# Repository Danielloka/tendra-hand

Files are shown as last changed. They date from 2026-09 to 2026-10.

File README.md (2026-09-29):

# Tendra Hand

**An open-source, tendon-driven, 3D-printed robotic hand, built to match the dexterity of a human hand.**

**The ultimate goal:** a robot that can do what humans do (cook, do chores, use tools) just as well as a person. Not only picking things up, but understanding a task and carrying it out. The hand is the focus, because almost everything useful people do goes through their hands, and it is the hardest part to get right.

Tendra Hand starts there: a hardware + software project to build a humanoid robotic hand with the same degrees of freedom as a human hand, then the senses and AI to use it for real tasks, and to share *everything* openly: CAD files, printable parts, firmware, control software, simulation, AI models and research notes.

> 🚧 **Status: early prototype.** Phase 1: the V0 thumb and index finger are built (8 independently driven joints); focus is smooth, clean motion and a MuJoCo digital twin. Phase 2: **Tendra Hand V1**, the first full hand (5 fingers, 20 joints, smart servos), is designed and simulated, not built yet. See the [roadmap](docs/roadmap.md).

## How it works

```
┌──────────────────────────┐   USB-C (serial)   ┌───────────────────────┐        ┌──────────────┐
│ PC (Python)              │ ─────────────────▶ │ ESP32-S3              │ ─────▶ │ Motors       │
│ • high-level control     │    joint targets   │ • low-level motor     │        │ → tendons    │
│ • AI / learning          │ ◀───────────────── │   control (firmware)  │        │ → joints     │
│ • MuJoCo digital twin    │    joint states    │ • hardware abstraction│        └──────────────┘
└──────────────────────────┘                    └───────────────────────┘
```

- **Mechanics:** PLA/PETG printed skeleton (TPU fingertip pads planned). Each joint is pulled both ways by a tendon loop on its own motor.
- **Actuators:** 28BYJ-48 steppers + ULN2003 drivers today → Feetech **SCS0009** smart servos (serial bus, position feedback) next.
- **Controller:** ESP32-S3, firmware built with PlatformIO.
- **Simulation:** [MuJoCo](https://mujoco.org/), with a digital twin that mirrors and can drive the real hand.

### Current prototype: 8 DOF

| Finger | Joints |
|---|---|
| Index | MCP side-to-side, MCP bend, PIP, DIP |
| Thumb | base rotation, CMC bend, MCP, IP |

## Repository layout

| Folder | Contents |
|---|---|
| [`hardware/`](hardware/) | CAD (Fusion 360 + STEP), print files, electronics, robot description (URDF) |
| [`firmware/`](firmware/) | ESP32-S3 firmware (PlatformIO) |
| [`sim/`](sim/) | MuJoCo models, model converter, digital twin |
| [`software/`](software/) | PC-side Python: hand API, control, calibration, AI |
| [`docs/`](docs/) | Roadmap and guides |
| [`research/`](research/) | Research log, experiments, references |
| [`website/`](website/) | Project website source |
| [`media/`](media/) | Photos, videos, screenshots and diagrams of the project, with a catalog |

## Getting started

Build and setup guides will be added as each part matures. For now:
- Robot model: [`hardware/robot_description/`](hardware/robot_description/)
- Plan: [`docs/roadmap.md`](docs/roadmap.md)
- Progress and findings: [`research/log.md`](research/log.md)

## Contributing

The project is in an early stage, but ideas, issues and questions are welcome. Open an issue on GitHub.

## License

Tendra Hand is open source, with a license suited to each kind of work:

| What | License | File |
|---|---|---|
| Software: firmware, Python, simulation, AI code and models | [Apache-2.0](https://www.apache.org/licenses/LICENSE-2.0) | [`LICENSE`](LICENSE) |
| Hardware: CAD, print files, electronics, robot description (`hardware/`) | [CERN-OHL-S-2.0](https://ohwr.org/cern_ohl_s_v1.txt) | [`hardware/LICENSE`](hardware/LICENSE) |
| Documentation and research (`docs/`, `research/`, website content) | [CC BY 4.0](https://creativecommons.org/licenses/by/4.0/) | [`docs/LICENSE`](docs/LICENSE) |

In short: you may use, build, modify and sell Tendra Hand. If you distribute a modified *hardware* design, you must share its design files under the same license. Please credit the project.

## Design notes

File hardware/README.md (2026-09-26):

# Hardware

Everything physical about Tendra Hand: mechanical design, printable parts, electronics and the robot description.

| Folder | What goes there |
|---|---|
| `cad/` | Source CAD: Fusion 360 `.f3d` files plus neutral **STEP** exports (STEP opens in any CAD program) |
| `print/` | Ready-to-print **STL/3MF** files and print settings (material, infill, orientation) |
| `electronics/` | Wiring diagrams, pinouts, power budget, bill of materials (BOM) |
| `robot_description/` | Robot model files (URDF) exported from CAD, used by `sim/` |

Hardware changes are logged in `research/log.md`.

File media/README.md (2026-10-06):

# media/

All photos, videos, screenshots and diagrams of Tendra Hand live here. It's the single place for
project pictures: the website, the READMEs, the research log and Claude all use these files.

```
media/
  inbox/          drop new, unprocessed files here (not committed to git)
  photos/         photos of the real hardware
  videos/         short clips (MP4), each with a poster frame in photos/
  screenshots/    MuJoCo viewer, Fusion, website, terminal output
  diagrams/       wiring diagrams, drawings, charts (SVG or PNG)
  catalog.json    one entry per file: what it shows, alt text, caption, date, tags
  process_inbox.py  prepares the files in inbox/ and adds them to the catalog
```

## Adding pictures

1. Copy the files into `media/inbox/`. Anything straight from the phone or camera is fine.
2. Run:

   ```sh
   uv run python media/process_inbox.py
   ```

   For each picture, the script:
   - rotates it upright and shrinks it to at most 2000 px on the long side
   - **removes EXIF metadata, including GPS location** (important: the repo is public)
   - saves it as a JPEG (PNG stays PNG, so screenshots stay sharp) with a clean name like
     `2026-09-29-img-4312.jpg` in the right folder
   - adds an entry to `catalog.json` with `"todo"` fields for the description

   Videos (`.mp4`, `.mov`, `.webm`) are only moved and catalogued, not shrunk. Keep clips short
   (5–20 s) and under ~10 MB. HEIC photos (iPhone) need an extra package:
   `uv run --with pillow-heif python media/process_inbox.py`.
3. Fill in the `todo` fields in `catalog.json`, or ask Claude: *"describe the new pictures in
   media/"*. Claude looks at each file, writes the description, alt text and caption, gives it a
   better name and suggests where to use it.

Or skip the script and just tell Claude *"process the media inbox"*.

## catalog.json

Each entry describes one file. It's what lets someone (or Claude) find the right picture without
opening every file.

| Field | Meaning |
|---|---|
| `file` | Path inside `media/`, e.g. `photos/2026-09-29-index-prototype.jpg` |
| `type` | `photo`, `video`, `screenshot` or `diagram` |
| `date` | When it was taken (from the photo, otherwise the day it was added), `YYYY-MM-DD` |
| `hand` | `v0`, `v1` or `null` if it's not about one hand version |
| `description` | What's in the picture, in detail, for people and for Claude |
| `alt` | Short alt text for screen readers (one sentence) |
| `caption` | Caption to show under it on the website |
| `tags` | Topics, e.g. `index`, `thumb`, `tendons`, `electronics`, `sim`, `cad`, `printing` |
| `width`, `height` | Size in pixels (filled in by the script) |
| `poster` | Videos only: the poster frame, e.g. `photos/...-poster.jpg` |
| `used_in` | Where it's used, e.g. `website/content/data/gallery.json` |
| `todo` | What's still missing; remove it when the entry is complete |
| `public` | Optional. `false` keeps the file off the website (e.g. people who haven't agreed to be online); the website only publishes files listed here |

## Using a picture

- **Website:** the files are copied to `website/public/media/` before `npm run dev` and
  `npm run build` (`website/scripts/sync-styleguide.mjs`), so `media/photos/a.jpg` is served at
  `/media/photos/a.jpg`. Use that path in `content/data/gallery.json`, `<Figure src=… />` in MDX,
  or a log post's `cover:`. Copy `alt`, `caption`, `width` and `height` from the catalog.
- **Markdown in the repo:** link with a relative path, e.g. from `research/log.md`:
  `![Index prototype](../media/photos/2026-09-29-index-prototype.jpg)`.

Experiment folders in `research/experiments/` can keep their own generated plots. Photos of the
hardware go here.

## Rules

- Never commit a photo that still has GPS data. Run the script, or strip EXIF another way.
- Don't show people's faces or private homes without their permission.
- Names: `YYYY-MM-DD-short-subject.ext`, lowercase, hyphens.
- Licence: like the other docs and research material, the media is CC BY 4.0 (`docs/LICENSE`).

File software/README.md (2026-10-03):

# Software

PC-side Python for Tendra Hand: the `tendra` package. It holds everything that talks to the hand, real or simulated, and later the control and AI code.

## The `Hand` API

The same interface works on the simulation and on the real hand, so a script or AI policy written for one runs on the other:

```python
from tendra import RealHand, SimHand

hand = SimHand()  # MuJoCo simulation
# hand = RealHand()              # real hand; finds the ESP32 on USB automatically

hand.set_joint("index_pip", 0.8)  # radians, positive = closing
hand.set_targets([0.5] * 8)  # all joints, motor order M1..M8
print(hand.positions())
```

## Two hands: v0 and v1

| Variant | Joints | Motors | Firmware config | MuJoCo model |
|---|---|---|---|---|
| `v0` | 8 (index + thumb) | 28BYJ-48 steppers, open loop | `firmware/include/config.h` | `sim/models/tendra_hand.xml` |
| `v1` | 20 (all five fingers, 4-DOF thumb) | Feetech SCS0009 servos, 16 servos, IDs 1–16 = motor order (finger DIPs are coupled to the PIPs) | `firmware/include/config_v1.h` | `sim/models/tendra_hand_v1.xml` |

Each variant is a `HandSpec` in `tendra/joints.py` (`V0`, `V1`, or `get_hand("v1")`): joint names, limits, model path, servo IDs. Every hand object has a `.spec`, so `hand.joint_names` and `hand.num_joints` always fit the hand in use. The old module constants (`JOINT_NAMES`, `NUM_JOINTS`, `JOINT_LIMITS`, `MODEL_PATH`) still describe v0.

```python
from tendra import RealHand, SimHand

sim = SimHand(hand="v1")  # the 20-joint model
hand = RealHand()  # the variant is read from the firmware's "I" line
print(hand.spec.name)  # "v0" or "v1"; RealHand(hand="v1") refuses a v0 board

# v1 only: the servos measure where they are
hand.positions()  # measured positions (S); on v0 these are counted steps
for fb in hand.feedback():  # F: position, load %, temperature, voltage per joint
    print(fb.name, fb.position, fb.load, fb.temperature, fb.voltage, fb.online)
hand.scan_bus()  # B: IDs of the servos that answer, e.g. [1, 2, 3, ...]
hand.info()  # I: per joint scale, zero_ticks, online (for calibration)
hand.offline_mask  # after set_targets: servos that did not take it (bit i = joint i)
```

Offline servos (unplugged, no power) report `nan` in `feedback()` and ignore `set_targets` (see `offline_mask`); `raw_move` (`M`) and `J` commands to them raise `HandError`. v1 servos start limp and switch on at their measured position with the first target, so nothing jumps.

| Module | What it is |
|---|---|
| `tendra/joints.py` | Joint names, order and limits per hand variant (`HandSpec`, `V0`, `V1`): the single Python source of truth |
| `tendra/hand.py` | `Hand` base class (the interface) |
| `tendra/real_hand.py` | `RealHand`: USB serial to the ESP32 firmware, variant auto-detect, v1 feedback (`feedback`, `scan_bus`, `info`), plus calibration helpers (`zero`, `raw_move`, `set_scale`, `set_limits`) |
| `tendra/sim_hand.py` | `SimHand`: the same API on MuJoCo; `step()`/`wait()` advance the physics; `set_positions()` puts the joints at a measured pose (digital-twin mirror) |
| `tendra/retarget.py` | **Retargeting**: 21 human hand landmarks → Tendra joint angles. Fingers by direct angle measurement, thumb by damped-least-squares optimisation on the MuJoCo model (with pinch handling), One Euro smoothing, open-hand calibration. Works for v0 and v1 |
| `tendra/lite_model.py` | `load_lite_model(path)`: the same model with simplified meshes (~15 % of the triangles, masses copied), much faster to draw. `SimHand(..., lite=True)` |
| `tendra/hand_view.py` | `HandView`: draws the hand into an image on demand (offscreen renderer), mirrored, with mouse rotate/zoom, or from a fixed model camera (`camera="view"`). For OpenCV windows |
| `tendra/arm.py` | The two-arm robot: `load_arm_model()` (OpenArm v2 shoulders and elbows + Tendra forearm, wrist and V1 hands, `right_`/`left_` names), `ik_model(side)` (bare kinematic copy), `ArmIK` (damped-least-squares IK: wrist pose to arm joint targets), `POSES` |
| `tendra/scene.py` | `GraspScene`: two arms with their hands behind a table (the floating hand is gone), one hand works per episode, the other sleeps; `canon_*` mirror helpers (the left hand is seen as a right hand), objects, cameras `view`, `right_wrist`, `left_wrist`, `set_wrist_target(pos, quat, side)`, `lifted()` success check, `scripted_grasp()` |
| `tendra/synergy.py` | Hand synergies (eigengrasps): `default_synergies()` (6 human-like patterns: close, oppose, spread, hook, roll, thumb curl), `fit_synergies()` (PCA from recorded postures), `project`/`residual` |
| `tendra/grasp_env.py` | `GraspEnv`: the RL environment on `GraspScene` (actions: wrist velocity + synergies + residual; actor/critic observations; human-like reward; domain randomisation; demo-state resets from scripted grasps or teleop datasets) |
| `tendra/rl/` | `ppo.py` (PPO with asymmetric critic, normalisation, adaptive LR; `Policy` for deployment), `vec_env.py` (envs in worker processes), `train.py` (trainer with object/demo/penalty curriculum, checkpoints, `progress.csv`) |
| `tendra/wrist.py` | `WristTracker`: the operator's wrist pose from the webcam. Hand translation by Gauss-Newton on the pinhole reprojection of MediaPipe's 3D landmarks, orientation from the palm frame, mirrored into the view frame; One Euro smoothing, clutch, gain |
| `tendra/dataset.py` | `EpisodeRecorder` (records the sim state per frame, cheap), `Dataset`, `load_episode`, `render_episode` (offline, by replay), `write_preview`. Format: `info.json`, `model.mjb`, `episodes.jsonl`, `episodes/episode_NNNNNN.npz` |
| `tendra/hand_tracking.py` | Webcam + MediaPipe Hand Landmarker (pretrained network, model downloaded to `~/.cache/tendra/`), drawing helpers |
| `tendra/fake_esp32.py` | Software stand-in for the ESP32, to test without hardware: `RealHand(connection=FakeEsp32())`. v1: `FakeEsp32(hand="v1", offline={9})` emulates the servo firmware, including offline servos and joints moved by hand while limp (`move_by_hand`) |

Tests: `uv run pytest` (from the repository root). They also check that the joint names and limits match the firmware (`config.h`, `config_v1.h`) and the MuJoCo models. The v1 model tests are skipped until `sim/models/tendra_hand_v1.xml` exists.

## Planned
- Calibration tool (guided, per joint), with results saved to a file
- Trajectory generation and grasp primitives (pinch, point, power grasp)
- Learning-based control, vision-based grasping (webcam teleop: done, `sim/teleop.py`)

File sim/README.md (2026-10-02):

# Simulation

**MuJoCo** models and tools for simulating the hand and running its **digital twin** (a simulated copy that mirrors, and can drive, the real hand).

## Quick start

From the repository root (needs [uv](https://docs.astral.sh/uv/)):

```bash
uv sync                          # create the Python 3.12 environment (first time only)
uv run python sim/view.py        # open the hand in the MuJoCo viewer
uv run python sim/view.py --v1   # open the full v1 hand (20 joints, tendon-driven)
uv run python sim/view.py --wrist  # v1 on its forearm: + forearm twist and a 2-way wrist
uv run python sim/view.py --arm  # both arms: OpenArm shoulder + elbow, then the Tendra forearm, wrist and v1 hand
uv run python sim/view.py --v1 --left  # the mirrored left hand (also --wrist --left)
uv run python sim/twin.py --fake # digital twin with a software ESP32
uv run python sim/twin.py --port auto   # digital twin driving the real hand
uv run python sim/twin.py --fake --hand v1          # v1 (20 joints) with a software ESP32
uv run python sim/twin.py --port auto --mirror      # v1: the sim follows the real hand
uv run python sim/teleop.py      # webcam teleop: your hand moves the v1 twin (--hand v0, --fake, --port)
uv run python sim/grasp_teleop.py                 # DISABLED until ported to the arm scene (prints why)
uv run python sim/export_lerobot.py ~/tendra-data/datasets/grasp-sim --preview   # MP4 previews
uv run --with "lerobot[dataset]" python sim/export_lerobot.py ~/tendra-data/datasets/grasp-sim --repo-id tendra/grasp-sim --out <dir>
uv run python sim/train_grasp.py --run runs/grasp  # RL: the hand learns to grasp by itself (re-run = resume)
uv run python sim/train_grasp.py --hands right --run runs/right   # one hand only (default any: both arms, one policy)
uv run python sim/eval_grasp.py --run runs/grasp --watch   # success table / watch / --video / --record
uv run python sim/fit_synergies.py grasp-sim       # your own eigengrasps from teleop demos (for --synergies)
```

`--hand auto|v0|v1` picks the hand (auto: whatever the firmware reports, v0 without a hand). `--mirror` reverses the direction (real → sim): the sim shows the servos' measured positions and nothing is sent to the hand, so you can move the limp fingers by hand and watch. It needs position feedback, so v1 only.

Move the joints with the sliders under **Control** in the right-hand panel.

## Files

| File | What it does |
|---|---|
| `convert.py` | Turns the raw Fusion export (`hardware/robot_description/fusion_export/`) into `models/tendra_hand.xml` and fixes it along the way: PLA masses, recomputed inertias, joint names, sign convention, actuators |
| `models/tendra_hand.xml` | The generated MuJoCo model (**don't edit by hand**; re-run `convert.py`) |
| `convert_v1.py` | Turns the v1 export (`hardware/robot_description/v1_export/`: `hand_v1.json`, `meshes/`, optional `tendon_routes.json`) into `models/tendra_hand_v1.xml`: bodies, closing-positive axis signs, PLA masses, 42 tendon strands, 21 servo actuators |
| `models/tendra_hand_v1.xml` | The generated v1 model (**don't edit by hand**; re-run `convert_v1.py`) |
| `convert_v1_wrist.py` | Puts the v1 hand on its forearm (`models/tendra_hand_v1_wrist.xml`): `forearm_rot` (twist, OpenArm's J5 motor), a 2-way wrist gimbal (`wrist_flex`, `wrist_dev`) in a 20 mm gap between forearm and palm. Every servo strand runs through one site on the wrist centre (PTFE sheaths through a hollow wrist), so wrist motion never changes a strand's length. Input is the generated `tendra_hand_v1.xml`, so it follows every `convert_v1.py` change |
| `models/tendra_hand_v1_wrist.xml` | The generated wrist model (**don't edit by hand**; re-run `convert_v1_wrist.py`). The full arm (OpenArm + this) is built in Python: `tendra.arm` |
| `convert_v1.py --side left`, `convert_v1_wrist.py --side left` | Build the mirrored left hand and wrist (`models/tendra_hand_v1_left.xml`, `tendra_hand_v1_wrist_left.xml`) from `hardware/robot_description/v1_export_left/` (made by `hardware/cad/mirror_export.py`). With no `--side` both sides are built |
| `view.py` | Interactive viewer (`--v1` full hand, `--wrist` on its forearm, `--arm` both arms, `--left` the mirrored left hand) |
| `twin.py` | **Digital twin**: slider targets are sent to the real hand (rate-limited, only on change); the terminal shows real-vs-sim difference. v1 adds `--mirror` (real → sim) |
| `teleop.py` | **Webcam teleoperation**: MediaPipe hand tracking → `tendra.retarget` → the twin (and optionally the real hand). One window: camera image + the hand, drawn only when it moves (≤ 30 fps). Defaults are tuned for a slow laptop: kinematic mode (no servo delay; `--physics` for the tendon sim), simplified meshes, no shadows, tendons hidden (`--tendons`), MuJoCo's viewer only with `--viewer`. Mouse on the hand: drag rotates, wheel zooms. Prints a speed summary on exit. Keys in the camera window: C calibrate (hand open and flat), SPACE pause, M flip palm side, Q quit |
| `grasp_teleop.py` | **Disabled** (2026-10-02): the webcam grasp teleop drove the floating hand, which was removed. It is a stub that explains this; the old version is in git history. To port: map the webcam wrist pose to `scene.set_wrist_target(pos, quat, side)` with a pose the arm can reach |
| `export_lerobot.py` | Renders recorded episodes offline (replaying the saved sim state) and exports them to a Hugging Face **LeRobot** dataset (v3.0 format, lerobot 0.6.1, run with `uv run --with "lerobot[dataset]"`), or only MP4 previews (`--preview`). Successful episodes only unless `--all` |
| `train_grasp.py` | **Reinforcement learning:** PPO trains the V1 hand on its arm (OpenArm's shoulder and elbow + Tendra's forearm and wrist; two arms, `--hands right|left|any`, one policy for both via a mirror) to grasp and lift (`tendra.grasp_env`, `tendra.rl`): synergy actions, human-like rewards, demo-state starts, object and penalty curriculum, domain randomisation, parallel worker processes. Writes `runs/<name>/` (`progress.csv`, `latest.pt`, `best.pt`); `--smoke` for a 30 s check. Design and research: `research/ai/grasp-rl.md` |
| `eval_grasp.py` | Evaluates a trained policy on fixed spawns (success, lift, time, smoothness, effort, synergy residual); `--watch` live window, `--video out.mp4`, `--record <name>` saves successful rollouts as a teleop-format dataset (RL teacher → imitation student) |
| `fit_synergies.py` | PCA "eigengrasps" from recorded teleop datasets → `.npz` for `train_grasp.py --synergies` |
| `tests/` | Model sanity checks, twin, mirrored left hand (`test_v1_left.py`): `uv run pytest` |

After a new Fusion export, or a change to `convert.py` / `convert_v1.py`:
```bash
uv run python sim/convert.py && uv run pytest       # v0
uv run python sim/convert_v1.py && uv run python sim/convert_v1_wrist.py && uv run pytest    # v1 (+ wrist)
```
The tests fail if a generated model is out of date.

## Model conventions

- Joints and actuators are listed in **motor order** (M1…M8): `index_dip, index_pip, index_mcp_flex, index_mcp_abd, thumb_ip, thumb_mcp, thumb_cmc_flex, thumb_cmc_rot`
- **Positive = closing the hand**, and 0 = straight. Angles are in radians.
- Actuators are simple position controllers standing in for the stepper + tendon, and will be tuned against the real hand later.

## v1 model (full hand, tendon-driven)

- **20 joints, 16 actuators** in **servo-ID order** (same as `firmware/include/config_v1.h`): `index_pip, index_mcp_flex, index_mcp_abd, thumb_ip, thumb_mcp_flex, thumb_cmc_flex, thumb_cmc_rot`, then middle, ring, little (`pip, mcp_flex, mcp_abd` each). Actuator names = joint names. The four finger DIPs have no actuator: each follows its PIP (DIP ≈ 0.75 × PIP) through a joint equality `<f>_dip_coupling` that uses the coupling linkage's exact curve (`hardware/cad/dip_linkage.py`).
- **Sign convention** (positive = closing), worked out automatically from the geometry, because Fusion's axis signs are arbitrary: finger flexion bends toward the palm (-Y); finger `mcp_abd` moves toward the thumb (+X); `thumb_cmc_rot` swings the thumb across the palm (-X); thumb flexion (`cmc_flex`, `mcp_flex`, `ip`) curls it toward the fingers (+Z).
- **Tendons.** Every servo joint has one loop of two strands, `<joint>_flex` and `<joint>_ext` (32 strands). The loop wraps a drum on the joint's child segment (7 mm for finger `mcp_flex`, 7.5 mm for `thumb_cmc_rot`, 6 mm otherwise) and is tied to it, so the joint changes the strand length by exactly the drum radius per radian: the flex strand shortens and the ext strand lengthens by the same amount, and the loop stays tight. Strands of more distal joints cross every joint they pass **exactly on its axis**, so those joints don't change their length (no coupling). In the palm and forearm the strands follow `tendon_routes.json` down to the spool tangent points. Each finger's DIP-PIP coupling bar is a grey passive tendon `<f>_dip_link` between its two pins (on the proximal and distal phalanges); its length stays constant along the coupling curve (tested), which checks the linkage geometry.
- **Actuation.** One actuator per servo pulls its joint's flex strand. `ctrl` is the **joint angle in radians** (0 = joint straight); the servo turns `servo_per_joint` = drum / 5 mm spool times that (1.2–1.5). The gains are SCS0009-like: kp 2 N·m/rad, torque limit 0.095 N·m at the servo (half of stall, ≈19 N of tendon force), both scaled to the joint by the ratio. MuJoCo tendons can push as well as pull, so one actuator on the flex strand stands in for the whole loop. Pretension, friction and line stretch are not modelled.
- Keyframes `open` and `fist`.
- **Known limits:** collisions use convex hulls. Palm ↔ thumb_metacarpal is excluded because the palm's hull fills the pocket for the thumb base. The real parts only meet near `thumb_cmc_flex` = 80°, which the sim therefore misses. Toward a straight neighbour, a finger can adduct only about 4–5° before touching it (8 mm gap). That is real geometry.

NVIDIA Isaac Sim/Lab may be added later on a machine with an NVIDIA GPU.

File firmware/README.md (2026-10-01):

# Firmware

Low-level motor control running on the **ESP32-S3-N16R8**, built with **PlatformIO** (Arduino framework, C++17).
The PC sends joint targets in radians over **USB-C** (native USB serial). The ESP32 moves the motors there smoothly.

One code base builds firmware for two hands:

| Build env | Hand | Joints | Motors | Config |
|---|---|---|---|---|
| `tendra_s3` (default) | **v0** prototype (thumb + index) | 8 | 28BYJ-48 steppers + ULN2003 boards | `include/config.h` |
| `hand_v1_servo` | **v1** full hand | 20 | Feetech **SCS0009** smart servos on one bus, via the **FE-URT-1** | `include/config_v1.h` |

## Build, flash, talk to it

From this folder (`firmware/`), or use the PlatformIO buttons in VS Code:

```bash
pio run                          # build v0 (the default env)
pio run -e hand_v1_servo         # build v1
pio run -t upload                # flash v0 (ESP32 on USB-C); add -e hand_v1_servo for v1
pio device monitor               # type commands, see replies (Ctrl+C to quit)
```

If the upload can't connect: hold **BOOT**, tap **RESET**, release BOOT, and try again.

## How it's built

| File | Role |
|---|---|
| `include/config.h` | v0: **pin map**, joint names/limits (same order as the sim), speed/acceleration defaults |
| `include/config_v1.h` | v1: servo IDs, joint names/limits, calibration defaults, bus pins/baud, speed limits |
| `src/motor_driver.h` | **HAL interface**: one joint actuator, in radians, with optional feedback. The rest of the code only uses this. |
| `src/uln2003_stepper.*` | v0: 28BYJ-48 + ULN2003 driver (half-step), implements `MotorDriver` |
| `src/scs0009_servo.*` | v1: SCS0009 servo driver, implements `MotorDriver` |
| `src/scs_protocol.h` | v1: SCS packet building, checksum, reply parser, register map (pure C++) |
| `src/scs_bus.*` | v1: `ScsBus` — ping, read/write registers, sync write, feedback; over an abstract byte port |
| `src/scs_uart_port.h` | v1: the byte port on an ESP32 hardware UART |
| `src/servo_calibration.h` | v1: joint angle ↔ servo ticks (scale, zero, direction) |
| `src/motion_profile.h` | Smooth motion: accelerate, cruise, brake (trapezoidal profile), handles new targets mid-move. Used by both hands. |
| `src/main.cpp` | Safe startup, main loop, serial command protocol (v0/v1 picked by `TENDRA_HAND_V1`) |
| `test/host/` | Unit tests that run on the PC (motion profile; SCS protocol, bus, calibration and servo driver) |

## Serial protocol (text, one command per line)

The same protocol for both hands; only the number of joints *N* changes (v0: 8, v1: 20).
Joints are numbered **1–N = motors M1–MN** (v1: motor number = servo ID). Angles are in **radians**, and **positive = closing the hand**.

- v0 joints: `index_dip, index_pip, index_mcp_flex, index_mcp_abd, thumb_ip, thumb_mcp, thumb_cmc_flex, thumb_cmc_rot`
- v1 joints: `index_dip, index_pip, index_mcp_flex, index_mcp_abd, thumb_ip, thumb_mcp_flex, thumb_cmc_flex, thumb_cmc_rot, middle_dip, middle_pip, middle_mcp_flex, middle_mcp_abd, ring_dip, ring_pip, ring_mcp_flex, ring_mcp_abd, little_dip, little_pip, little_mcp_flex, little_mcp_abd`

| Command | Meaning | Reply |
|---|---|---|
| `P q1 … qN` | set all N targets | `OK` (v1: `OK offline <mask>` if some servos don't answer; those don't move) |
| `J i q` | set target of joint *i* | `OK` (v1: `ERR joint offline`) |
| `S` | status | `S q1 … qN moving_mask`. v0: counted steps. **v1: measured positions** (real → sim) |
| `F` | feedback, per joint `q,load,temp,volt` | `F 0.1234,12.5,31,5.0 …`; `nan,0,0,0` if the joint has no data (always on v0). *load* is % of max torque, positive = pulling toward closing; *temp* °C; *volt* V |
| `X` | stop all, smoothly | `OK` |
| `R` | release all: v0 coils off, **v1 torque off** (joints go limp) | `OK` |
| `Z` | current pose = zero | `OK` |
| `M i n` | raw move joint *i* by *n* native units, **ignores joint limits** (calibration). v0 steps (max ±4096), v1 servo ticks (max ±300, still kept inside 0–1023) | `OK` |
| `K i s` | set joint *i* scale in native units per joint radian (v0 steps/rad, v1 ticks/rad) | `OK` |
| `V i v a` | max velocity (rad/s) and acceleration (rad/s²) of joint *i* (`0` = all) | `OK` |
| `B` | **v1 only:** scan the bus (IDs 0–253, ~0.4 s) | `B 1 2 3 …` (IDs that answered) |
| `I` | firmware info + scales | v0: `I tendra-hand fw 0.1.0 joints=8 name:scale …`; v1: `I tendra-hand fw 0.4.0 hand=v1-servo joints=16 name:ticks_per_rad:zero_ticks:online …` |

Targets are clamped to the joint limits. v0: coils switch off after 1 s without motion. v1: servos keep holding (torque on) until `R`.

## v1: SCS0009 servos

### Wiring (FE-URT-1 as signal converter)

| ESP32-S3 | FE-URT-1 | Notes |
|---|---|---|
| GPIO **17** (UART1 TX) | TX | |
| GPIO **18** (UART1 RX) | RX | |
| GND | GND | common ground with the servo supply |

GPIO 17/18 are ordinary pins: not strapping pins (0, 3, 45, 46), not native USB (19/20), not UART0 (43/44), not flash/PSRAM (26–37), not the RGB LED (48). Change them in `config_v1.h`.
Some FE-URT-1 boards have TX/RX **silk-screened the wrong way round**: if `B` finds nothing, swap the two wires.
The FE-URT-1 switches the half-duplex bus direction by itself. If it echoes our own bytes back to RX, `ScsBus` skips the echo automatically.
Bus: **1,000,000 baud**, 8N1 (the SCS0009 default). Every servo needs a unique ID = its motor number (1–20); set IDs one servo at a time with Feetech's FD software over the FE-URT-1's USB port.
Power the servos from their own supply (SCS0009: 4–7.4 V). 16 servos under load draw several amps: size the supply and wiring for it, and keep the ESP32 on USB.

### How it moves

- Each servo has an **absolute position sensor** (0–1023 ticks over ~300°, ≈195.6 ticks/rad, centre 512). No homing is needed; the firmware always knows where each joint is.
- The firmware ramps each goal with the same trapezoidal profile as v0 (one tick at a time, ≤ 400 ticks/s) and streams the goals of all moving servos every **20 ms** in one **SYNC WRITE** packet. So even a big target jump becomes a smooth, speed-limited move.
- As a second limit, every goal carries the servo's **goal speed** register (`kServoGoalSpeed`, never 0, because 0 means "full speed").
- Feedback (position, load, voltage, temperature) is read from one servo every 2 ms, round robin (all 20 in ~40 ms). A servo that misses 3 replies counts as **offline** and is only retried once per second.

### Calibration: joint angle ↔ servo ticks

`ticks = zero_ticks + (invert ? -1 : 1) · ticks_per_rad · q`, with `ticks_per_rad = servo_per_joint · 195.57`.

- `servo_per_joint` = servo radians per joint radian = *r*<sub>joint drum</sub> / *r*<sub>spool</sub> (same tendon length both sides). Set from the design (since 0.4.0): 5 mm spools on every servo, so **1.4** for finger `mcp_flex` (7 mm drum), **1.5** for `thumb_cmc_rot` (7.5 mm) and **1.2** for the rest (6 mm); calibrate per joint once built. The finger DIPs have no servo (coupled to the PIP), so V1 has 16 servos for 20 joints.
- `zero_ticks` = servo reading with the joint straight. Default 512 (servo centred when the tendon is tied).
- `invert` if more ticks opens the joint.

### v1 safety rules

- **Never moves on boot.** `setup()` broadcasts *torque off* to every servo, then switches each one off again and reads its position. Nothing moves until a `P`/`J`/`M` command.
- On the first command, a joint's goal is first set to **where it is now**, then torque comes on, then it ramps to the target. No jump.
- A servo that has **never answered cannot be switched on** (its position is unknown): `J`/`M` reply `ERR joint offline`.
- `R` = torque off for all (broadcast + each servo). `X` = smooth stop, holding position.
- The firmware only writes the SRAM registers (torque, goal position/time/speed). It never writes EPROM (ID, baud, angle limits).

### v1 first power-on checklist

1. Flash `hand_v1_servo` with **only USB connected**. Send `I`: 20 joints, all `:0` (offline).
2. Power the servos. Send `B`: it should list the IDs you connected. Send `I` again (online joints end in `:1`) and `F` to see positions, voltage and temperature.
3. Straighten the joints by hand (they are limp), then send `Z`, then `I`; copy the `zero_ticks` values into `config_v1.h`.
4. One joint at a time: `M i 30` (≈9° at the servo), then `M i -30`. Check that the right joint moves and **positive closes** it; otherwise set `invert = true` in `config_v1.h`.
5. Calibrate scale: `M i 150`, measure the joint angle, then `K i <150 / angle_in_rad>`. Write it into `config_v1.h` as `servo_per_joint = value / 195.57`.
6. Only then use `J i q` / `P ...`. Keep `R` ready (and a power switch).

## Safety rules (v0 steppers)

- At boot, all motor pins go LOW and **nothing moves until a command arrives**.
- **PSRAM must stay disabled**: GPIO 35–37 drive motors 6 and 7 (see `platformio.ini`).
- Steppers are open loop: the firmware *counts* steps. Straighten all joints by hand before power-up (or send `Z` after straightening).
- Stay near a power switch during first tests. A tendon that is too tight or a wrong direction can pull hard.

## First power-on checklist (v0, one motor at a time)

1. Flash with **only USB connected** (motor power off). Open the monitor and send `I`, which should list 8 joints.
2. Connect the motor power. Straighten all joints by hand, then send `Z`.
3. For each motor: send `M i 200` (a small move, ~18°), then `M i -200`.
   - Check that the right joint moves and that **positive closes** the joint. If it opens instead, set `invert = true` for that joint in `config.h`.
4. Calibrate scale: send `M i 1000`, measure the joint angle (in degrees), then `K i <1000 / angle_in_rad>`. Write the value down (it'll go into `config.h`).
5. Only then use `J i q` / `P ...` with real angles.

## Host tests

Run from `firmware/` (a throwaway C++ compiler from the `ziglang` Python package, no install needed):

```bash
uvx --from ziglang python -m ziglang c++ -std=c++17 -O2 -w -Isrc test/host/test_motion_profile.cpp -o .pio/test_motion_profile.exe && .pio/test_motion_profile.exe
uvx --from ziglang python -m ziglang c++ -std=c++17 -O2 -w -Isrc -Iinclude test/host/test_scs.cpp src/scs_bus.cpp src/scs0009_servo.cpp -o .pio/test_scs.exe && .pio/test_scs.exe
```

`test_scs.cpp` checks packet bytes and checksums against hand-computed values, the reply parser (noise, bad checksums), `ScsBus` against a fake servo bus with and without echo, angle ↔ tick conversion, and the servo driver's boot safety, ramp speed and limit clamping.

## Sources and licenses

The SCS code here is written from scratch (Apache-2.0, like the rest of the firmware). The protocol and register map were taken from Feetech's documentation and read (not copied) from the official [FTServo_Arduino](https://github.com/ftservo/FTServo_Arduino) library (`SCS.cpp`, `SCSCL.h/.cpp`). No third-party code is vendored.

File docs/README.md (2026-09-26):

# Docs

Project documentation: roadmap, build guides, assembly instructions, calibration and usage guides.

- `roadmap.md`: development phases, from thumb + index to full AI-controlled hand

This folder can also feed the project website.

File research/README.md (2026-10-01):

# Research

Research hub: lab notebook, experiments, references.

- `log.md`: dated research log (experiments, results, decisions, ideas)
- `ai/`: embodied-AI research hub: bimanual pole robot vision, AI architecture, staged roadmap, maths, resources, ideas
- `experiments/`: data and scripts for individual experiments
- `references/`: notes on papers and related projects
  - `references/hands/`: the state of the art in robot hands (1X NEO, humanoid company hands, ORCA/LEAP/Aero and other open-source hands, tendon mechanics, sensing, actuators and control). Start with its `README.md`, which has the overview and the prioritised plan for Tendra.

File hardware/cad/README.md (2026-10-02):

# CAD

Source design files for the hand.

- `*.f3d`: Fusion 360 archives (the source of truth)
- `*.step`: neutral exports so people without Fusion can open and modify the design
- `fusion_scripts/`: Fusion API scripts (see its README). `TendraHandV1/` builds the full v1 hand.
- `tendon_router.py`: v1 tendon routes + forearm servo layout (single source of truth for the CAD channels and the MuJoCo tendons). Run `uv run python hardware/cad/tendon_router.py`; tests in `tests/` (run by `uv run pytest`).
- `dip_linkage.py`: the DIP-PIP coupling bar of each V1 finger (pin positions found per finger from the middle-phalanx length in `hand_v1.json`, so DIP ≈ 0.75 × PIP). `tendon_router.py` writes the result into `tendon_routes.json` (`coupling.linkages`); `uv run python hardware/cad/dip_linkage.py` prints it.
- `mirror_export.py`: reflects `v1_export/` into `../robot_description/v1_export_left/` (the left hand for the two-arm sim; mirror plane x = -33.5 mm). `--check` reports if it is stale. Re-run after every `tendon_router.py` or Fusion export change.

When the design changes, export both, and re-export the URDF into `../robot_description/fusion_export/`.

## Tendra Hand V1

Fusion design **"Tendra Hand V1"** (a copy of "Hand assebly"). Workflow after a change:
1. `uv run python hardware/cad/tendon_router.py` (if routes/layout changed) and `uv run pytest hardware/cad/tests`
2. In Fusion, run the `TendraHandV1` stages (each skips itself if already applied), then stage `export`
3. `uv run python sim/convert_v1.py && uv run pytest`

- `spool_v0.py`: parametric tendon spool for the V0 hand's 28BYJ-48 steppers (OpenCASCADE, writes `hardware/print/v0/spool_r<radius>.stl`). Run: `uv run --with cadquery-ocp python hardware/cad/spool_v0.py [--radius 5]`.

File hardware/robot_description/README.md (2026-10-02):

# Robot description

Kinematic/physical models of the hand.

- `fusion_export/`: the **raw, unedited** export from Fusion 360 (made with the `fusion2urdf` plugin, a ROS 1 package format).
  Don't edit it by hand: re-export from Fusion instead, so nothing gets lost.
  Its `LICENSE` and `package.xml` are template leftovers from the plugin and don't describe this project.

- `v1_export/`: the v1 hand (20 joints, 16 servos), written by the `TendraHandV1` Fusion script (stage `export`): `hand_v1.json` (parts + joints, world mm, all joints at 0; Fusion's axis signs are arbitrary), `meshes/*.stl`, and `tendon_routes.json` from `hardware/cad/tendon_router.py`. `sim/convert_v1.py` turns it into `sim/models/tendra_hand_v1.xml`.
- `v1_export_left/`: the **mirrored left hand**, generated (don't edit) from `v1_export/` by `hardware/cad/mirror_export.py` (reflection across x = -33.5 mm, the hand's mirror plane; STL winding reversed). `uv run python hardware/cad/mirror_export.py` rebuilds it, `--check` fails if it is stale; `uv run pytest` checks that too. Re-run after every new `v1_export/`.

The cleaned models (correct PLA masses, recomputed inertias, descriptive joint names, flexion-positive axes, MuJoCo MJCF) are **generated** from this export by a script in `sim/`.

### Known issues in the current export
- Material is set to steel (total mass 821 g instead of about 130 g)
- Inertias rounded to 1e-6; two are invalid
- Placeholder effort/velocity limits (100)
- Thumb joints 7 and 8 have opposite axis signs

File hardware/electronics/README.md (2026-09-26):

# Electronics

Wiring, pinouts and power for the hand.

**Current setup (Phase 1):** ESP32-S3-N16R8, 8x 28BYJ-48 steppers, 8x ULN2003 drivers, separate 5 V / 2 A motor supply.
**Planned:** Feetech SCS0009 smart servos on one bus via an FE-URT-1 adapter.

The authoritative pin map lives in `firmware/` (config header) and `CLAUDE.md`. Keep diagrams here in sync with it.

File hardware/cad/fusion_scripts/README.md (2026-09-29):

# Fusion scripts

Python scripts that run inside Fusion (Autodesk Fusion API). Each script lives in its own folder with a `.py` and a `.manifest` of the same name.

**Run one:** Fusion → **Utilities → Scripts and Add-Ins** → **+** (add from device) → pick the script's folder → select it → **Run**.

Run design-changing scripts on a **copy** of the design, or check the version history afterwards.

| Script | What it does | Changes the design? |
|---|---|---|
| `TendraInspect` | Writes `inspect_output.txt` with components, bodies, joints and axis positions (world mm) | No |
| `TendraPipPinch` | Fills the fingertip tendon slot at the index PIP and adds a 1.2 mm hole on the joint axis (see `research/experiments/2026-09-27-pip-pinch/`) | Yes: 2 timeline features, asks first |
| `TendraIndexPinch` | Index knuckle: 1.4 mm hole on the MCP flex axis and a 1 mm slit on the sideways axis (see `research/experiments/2026-09-27-index-pinch/`). Needs the finger straight | Yes: 2 features per change, asks first |
| `TendraHandV1` | Builds the v1 hand in the "Tendra Hand V1" design, in stages: `fingers` (middle/ring/little from the index), `thumb` (keeps the 4-DOF thumb), `names`, `thumb_unhinge` (one-off: removes the 5th-DOF hinge from designs built before 2026-09-29), `thumb_base` (plate 4 mm lower, hollow journal, r 7.5 cmc_rot drum, hanger for the cmc_flex pin; see `research/experiments/2026-09-29-thumb-routing/`), `thumb_meta` (cmc_flex drum on the metacarpal, cleared around the strands), `palm` (full palm, deeper thumb bay with journal bearing and pin hole, 42 tendon channels), `forearm` (21 SCS0009 + spools, sheath stops in the wrist plate); `export` writes STLs + joints to `hardware/robot_description/v1_export/`. Reads `tendon_routes.json` | Yes: refuses to run on any other design |

Output files (`*_output.txt`) are not committed.

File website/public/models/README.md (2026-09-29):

# 3D models

The website shows a **procedural placeholder hand** until a real model is put
here. To switch to the real hand:

1. Export the model as `public/models/hand.glb` (steps below).
2. In `src/components/three/model.ts`, change the one line to
   `export const HAND_MODEL_URL: string | null = "/models/hand.glb";`
3. Open `/dev/hand` (the hand lab) and check every preset and joint slider.

Keep the file small: aim for **under 3 MB** (it loads on the homepage).

## Coordinate frame

| | |
|---|---|
| Up (+Y) | toward the fingertips (hand pointing up) |
| Toward the camera (+Z) | the **palm** side |
| +X | the **thumb** side (it's a right hand seen from the palm) |
| Units | metres (the site rescales the model to a fixed height anyway) |

## Node names (this is what makes the hand move)

Each joint needs an **empty/node named exactly like the joint**, sitting at the
joint's pivot. Everything that should move with the joint (the next finger
segment, and all segments after it) is a **child** of that node.

- The node's **origin** is the pivot point.
- The node's **local X axis** is the rotation axis.
- A **positive** rotation about local X is "closing the hand" (the project's
  sign convention, see `CLAUDE.md`): fingers bend toward the palm, the thumb
  swings across the palm, `index_mcp_abd` moves the index toward the thumb.
  If a joint bends the wrong way, flip that node's X axis in Blender
  (rotate the empty 180° about its Y or Z axis and re-parent).

Joint names (all 17; the first 8 exist on the real prototype):

```
thumb_cmc_rot  thumb_cmc_flex  thumb_mcp  thumb_ip
index_mcp_abd  index_mcp_flex  index_pip  index_dip
middle_mcp_flex  middle_pip  middle_dip
ring_mcp_flex    ring_pip    ring_dip
little_mcp_flex  little_pip  little_dip
```

Hierarchy example for the index finger:

```
palm
└─ index_mcp_abd        (empty at the knuckle)
   └─ index_mcp_flex    (empty at the knuckle)
      ├─ index_proximal (mesh)
      └─ index_pip      (empty at the middle joint)
         ├─ index_middle (mesh)
         └─ index_dip   (empty at the fingertip joint)
            ├─ index_distal (mesh)
            └─ index_tip    (optional empty at the fingertip)
```

Optional extras:

- `thumb_tip`, `index_tip`, `middle_tip`, `ring_tip`, `little_tip`: empties at
  the fingertips. The glowing tendon lines run through the joint nodes and end
  at these; without them a tendon ends at the last joint.
- The tendon lines sit ~1 cm behind each joint along the node's **local −Z**
  (the back of the hand), so keep local +Z pointing to the palm side.

What happens without the joint nodes: the model still shows, lights, glows
and turns, but nothing bends, and there are no labels, tendons or exploded
view.

How the effects use the nodes:

| Effect | Uses |
|---|---|
| Joint bending | rotation about local X, on top of the node's rest pose |
| Labels (MCP / PIP / DIP / CMC / IP) | pinned to the joint node's origin |
| Tendons | a curve through the joint nodes (+ `*_tip`), offset to the back |
| Exploded view | each joint node slides outward along its offset from its parent |
| Wireframe | automatic outline + sharp edges of every mesh |

Joint ranges (how far `1.0` on a slider turns) are in
`src/components/three/rig.ts` (`JOINT_RANGE`).

## Export: Fusion 360 → Blender → glTF

1. **Fusion 360:** export each body, or the whole design, as **OBJ** or
   **STEP**/**FBX** (File → Export). Use the assembly where each finger
   segment is its own body.
2. **Blender** (free): import it. Check the scale (1 unit = 1 m; Fusion often
   exports millimetres, so scale by 0.001 and apply the scale with
   Ctrl+A → Scale).
3. Rotate the hand so it matches the frame above (fingers up +Y, palm facing
   the front). Blender is Z-up; the glTF exporter converts to Y-up for you when
   **+Y Up** is ticked (the default).
4. Add an **Empty** (Shift+A → Empty → Plain Axes) at each joint, name it,
   rotate it so its X axis is the joint axis, and parent the segments to it as
   in the hierarchy above (select child, then parent, Ctrl+P → Object (Keep
   Transform)).
5. Reduce detail: a Decimate modifier (ratio 0.2–0.5) on dense CAD meshes, and
   apply it. Screws and tiny parts can go.
6. Materials: one simple Principled BSDF per material (the site adds its own
   lighting, rim glow and wireframe on top). No textures needed.
7. File → Export → **glTF 2.0**: Format **glTF Binary (.glb)**, Include →
   *Selected Objects* or *Visible Objects*, Transform → **+Y Up**, Data →
   Mesh: *Apply Modifiers*. **Draco compression** is optional: it makes the
   file much smaller, but the decoder is then downloaded from Google's CDN
   (gstatic.com) on first load.
8. Save as `public/models/hand.glb`, set `HAND_MODEL_URL`, and test in
   `/dev/hand`.

## Current model

`hand.glb` is made straight from the STEP file by a script (no Blender):

```
uv run --with cadquery-ocp --with pygltflib python website/scripts/step-to-glb.py
```

It reads `hardware/cad/Hand assebly.step` (thumb + index prototype, 9 parts,
~13k triangles, 0.4 MB) and rigs it automatically: each part is matched to a
body of the MuJoCo model (`sim/models/tendra_hand.xml`) by its bounding box, and
the joint nodes are placed at the URDF joint pivots with the sim's axis signs
(positive = closing). `index_tip` / `thumb_tip` mark the fingertips. The STEP
and the URDF export must come from the same Fusion design; the script stops
if a sim body has no matching part.

`index_mcp_abd` and `thumb_cmc_rot` have sideways axes, so the tendon line
skips them and runs through the next joint (see `gltfRig.ts`).

## `hand-v1.glb` (project page)

A **static, unrigged** model of the full 5-finger Tendra Hand V1 (palm, fingers and thumb, no servos
or forearm), shown spinning in the project page's hero (`components/three/SpinHand.tsx`). Made from
the Fusion export by `website/scripts/v1-to-glb.py` (command in its docstring); re-run it after a new
V1 export. About 1.6 MB.

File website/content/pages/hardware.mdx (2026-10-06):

---
title: Hardware
kicker: Build it yourself
lead: "Printed parts, small motors, one microcontroller and some cord. Here is what goes into the prototype and where to find the files."
description: "The parts, files, print settings, motors and electronics behind the Tendra Hand thumb and index prototype."
---

## What the prototype is made of

The current prototype is a thumb and an index finger with 8 joints. It has three layers:

<CardGrid>
  <Card title="Printed skeleton" kicker="Mechanics">
    The bones of the fingers, printed in PLA or PETG. Soft TPU fingertip pads are planned for a better grip.
  </Card>
  <Card title="Tendons" kicker="Motion">
    Each joint has one closed loop of cord wound on a spool with a 1 cm radius. The motor turns the spool one way to bend the joint and the other way to straighten it.
  </Card>
  <Card title="Motors and electronics" kicker="Power">
    8 small stepper motors, one per joint, each with its own driver board, all controlled by one ESP32-S3.
  </Card>
</CardGrid>

## Design files

All hardware files live in the [`hardware/`](https://github.com/Danielloka/tendra-hand/tree/main/hardware) folder on GitHub.

| Folder | What's inside |
|---|---|
| `hardware/cad/` | The source design: Fusion 360 files, plus STEP files that open in any CAD program |
| `hardware/print/` | Ready-to-print STL and 3MF files, with print settings |
| `hardware/electronics/` | Wiring, pin map and power budget |
| `hardware/robot_description/` | The robot model exported from Fusion 360, used by the simulation |

<Callout type="note" title="What is in the repository today">
  The repository holds the full hand as a STEP file (it opens in any CAD program), the Fusion 360 scripts that build the V1 design, the robot model with a 3D mesh of every part, and a spool you can print. A complete set of print-ready files is still being prepared and will be added to `hardware/print/`.
</Callout>

## Bill of materials

Everything needed for the thumb and index prototype, plus the planned servo upgrade.

<BomTable />

## Print settings

The final settings haven't been written down yet. These are common starting points for small mechanical parts, not tested values for this hand.

| Setting | Starting point |
|---|---|
| Material | PLA or PETG |
| Nozzle | 0.4 mm |
| Layer height | 0.2 mm (0.12 to 0.16 mm for small finger parts) |
| Walls | 3 or more perimeters, so joint holes stay strong |
| Infill | 20 to 40 % |
| Supports | Only where needed; orient parts to avoid them in joint holes |
| Orientation | Lay parts so layers don't split along the direction the tendon pulls |

The simulation model assumes solid plastic and works out to about 131 g. Real printed parts are lighter because they aren't solid.

## Motors

Each joint is driven by a **28BYJ-48** stepper motor (5 V) through a **ULN2003** driver board.

- A stepper motor turns in small, exact steps. This one has a built-in gearbox (about 63.7:1), so it makes about 4076 half-steps per turn of its output shaft.
- With the 1 cm spool, one turn pulls about 62.8 mm of cord. That is roughly 0.015 mm of cord per half-step.
- Top speed is about 15 turns per minute. Slow, but smooth and strong for its size.
- They are **open loop**: the motor doesn't report where it is. The firmware counts steps instead. So before power-up, every joint is straightened by hand, and that pose counts as zero.

How many steps it takes to bend each joint by a given angle depends on how the tendon wraps around that joint. That number is measured per joint during calibration.

### Next: smart servos

The plan is to replace the steppers with **Feetech SCS0009** smart servos. They report their own position, so no more straightening by hand. They also share one data cable instead of four wires each, connected to the ESP32-S3 through an **FE-URT-1** adapter.

## Electronics

| Part | Role |
|---|---|
| ESP32-S3-N16R8 | The microcontroller. Receives joint angles over USB-C and runs the motors |
| 8 × ULN2003 | Driver boards that switch the motor coils on and off |
| 5 V / 2 A supply | Powers the motors, separately from USB |

**Power budget.** Each motor draws around 200 to 250 mA per coil when it's switched on, so 8 motors come close to the 2 A limit. The firmware switches a motor's coils off after 1 second without motion.

**Pin notes for the ESP32-S3-N16R8.** 8 motors × 4 wires need 32 pins, which pushes this board to its limits:

- GPIO 35, 36 and 37 are normally used by the board's extra memory (PSRAM). They only work for motors because PSRAM is switched off in the firmware.
- GPIO 0 decides the boot mode at reset. The driver board can pull it low, which may stop the board from starting normally while motor 7 is connected.
- GPIO 43 is where the board prints startup messages, so motor 8 may twitch at reset. The firmware talks only over USB.
- GPIO 19 and 20 are the USB connection and are never used for motors.

The full pin map is in [`firmware/include/config.h`](https://github.com/Danielloka/tendra-hand/blob/main/firmware/include/config.h). The servo upgrade removes most of these problems, since all servos share one cable.

<Callout type="warning" title="Safety first">
  At startup, all motor pins are switched off and nothing moves until the computer sends a command. During first tests, stay near a power switch: a tendon that is too tight, or a motor turning the wrong way, can pull hard.
</Callout>

## Wiring diagram

Each motor connects to its own ULN2003 board, and each board to four pins on the ESP32-S3 (see the pin map in [Electronics](/docs/electronics#motor-and-pin-map)).

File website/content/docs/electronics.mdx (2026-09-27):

---
title: Electronics
description: The ESP32-S3 controller, ULN2003 motor drivers, the motor-to-pin map, pin warnings, flashing the firmware with PlatformIO, and the serial protocol.
updated: 2026-09-27
---

The electronics have one job: turn joint angles from your PC into smooth motor motion. The PC does the thinking (control, simulation, later AI); the microcontroller only moves the motors.

```text title="Signal path"
PC (Python)  --USB-C-->  ESP32-S3  -->  8 × ULN2003  -->  8 × 28BYJ-48  -->  tendons  -->  joints
```

## Parts

| Part | Qty | Notes |
|---|---|---|
| ESP32-S3-N16R8 board | 1 | 16 MB flash, 8 MB PSRAM (kept **off**, see below). USB-C to the PC. |
| ULN2003 driver board | 8 | One per motor. Switches the four motor coils. |
| 28BYJ-48 stepper, 5 V | 8 | Geared ≈ 64:1, ≈ 2038 full steps per output turn. |
| 5 V / 2 A power supply | 1 | For the motors only. Its ground must connect to the ESP32 ground. |

## Motor and pin map

Motors are numbered **M1 to M8**. This order is used everywhere: in the firmware, the serial protocol, the Python code and the simulation. IN1–IN4 are the four inputs on each ULN2003 board.

| Motor | IN1, IN2, IN3, IN4 (GPIO) | Joint | What it moves |
|---|---|---|---|
| M1 | 4, 5, 6, 7 | `index_dip` | Index fingertip joint |
| M2 | 15, 16, 17, 18 | `index_pip` | Index middle joint |
| M3 | 8, 3, 14, 9 | `index_mcp_flex` | Index knuckle bend |
| M4 | 10, 11, 12, 13 | `index_mcp_abd` | Index sideways |
| M5 | 1, 2, 42, 41 | `thumb_ip` | Thumb tip joint |
| M6 | 40, 39, 38, **37** | `thumb_mcp` | Thumb middle joint |
| M7 | **36, 35, 0**, 45 | `thumb_cmc_flex` | Thumb base bend |
| M8 | **48**, 47, 21, **43** | `thumb_cmc_rot` | Thumb base rotation |

**Sign convention:** positive angles close the hand, negative angles open it, and 0 is the joint held straight. For the thumb base rotation, positive swings the thumb across the palm. For the index sideways joint, positive moves the index toward the thumb.

## Pin warnings

The pins in **bold** above need care. They work, but only because of choices in the firmware:

<Callout type="warning" title="GPIO 35, 36, 37: PSRAM must stay off">
  On the N16R8 module these pins are wired to the 8 MB PSRAM chip. They can drive motors 6 and 7 only because PSRAM is **disabled** in the firmware build (`platformio.ini`). Never enable PSRAM with this pin map.
</Callout>

- **GPIO 0** (M7) is a *strapping pin*: if it's held LOW at reset, the chip starts in download mode instead of running the firmware. The ULN2003 input may pull it low, so the board might not boot normally with motor 7 connected. This hasn't been tested on the real hand yet; if you run into it, please open an issue. The servo upgrade (below) frees this pin.
- **GPIO 43** (M8) is the chip's UART0 transmit pin. The boot ROM prints messages on it at reset, so motor 8 may twitch briefly. The firmware never logs on UART0; it talks over USB instead.
- **GPIO 48** (M8) is often wired to the board's RGB LED. The firmware doesn't drive the LED.
- **GPIO 3 and 45** are strapping pins too, but LOW is already their default, so they're fine.
- **GPIO 19 and 20** are the native USB pins. Never use them for motors.

The firmware sets every motor pin LOW (all coils off) as the very first thing it does.

## Power

Each energised 28BYJ-48 draws about 200–250 mA, so eight at once would be close to the 2 A supply's limit. To stay within budget, the firmware **switches off a motor's coils after 1 s without motion**. The motor's internal gearbox mostly holds the joint in place without power.

## Flashing the firmware

The firmware is a [PlatformIO](https://platformio.org/) project (Arduino framework, C++17) in `firmware/`. Install PlatformIO as a VS Code extension or as a command-line tool, then from the `firmware/` folder:

```sh title="Terminal"
pio run                 # build
pio run -t upload       # flash (ESP32 on USB-C)
pio device monitor      # type commands, see replies (Ctrl+C to quit)
```

<Callout type="tip">
  If the upload can't connect: hold **BOOT**, tap **RESET**, release BOOT, and try again.
</Callout>

## Serial protocol

The PC talks to the ESP32 with short text commands, one per line. Joints are numbered 1–8 (= M1–M8), angles are in **radians**, and positive closes the hand. Every command replies `OK` unless noted.

| Command | What it does |
|---|---|
| `P q1 … q8` | Set targets for all 8 joints |
| `J i q` | Set the target of joint *i* |
| `S` | Status. Replies `S q1 … q8 moving_mask` |
| `X` | Stop all joints, smoothly |
| `R` | Release all coils (joints go limp) |
| `Z` | The current pose becomes zero |
| `M i n` | Raw move of joint *i* by *n* steps, **ignoring limits** (calibration only; max ±4096) |
| `K i s` | Set joint *i*'s scale in steps per radian (calibration) |
| `V i v a` | Max velocity (rad/s) and acceleration (rad/s²) for joint *i* (`0` = all joints) |
| `I` | Firmware info and scales |

Targets are clamped to each joint's limits. Moves speed up and slow down smoothly (a *trapezoidal* profile), and a new target can arrive mid-move. You rarely need to type these by hand: the Python `RealHand` class sends them for you.

## First power-on

Do this one motor at a time, with a hand near the power switch.

<Steps>
  <Step title="Flash with only USB connected">
    Keep the motor power off. Open the monitor and send `I`. It should list 8 joints.
  </Step>
  <Step title="Power the motors and zero">
    Switch on the motor power. Straighten every joint by hand, then send `Z`.
  </Step>
  <Step title="Check each motor's direction">
    For each motor *i*, send `M i 200` (a small move, about 18°), then `M i -200`. Check that the right joint moves and that **positive closes** it. If it opens instead, set `invert = true` for that joint in `firmware/include/config.h`.
  </Step>
  <Step title="Calibrate the scale">
    Send `M i 1000`, measure how far the joint turned, convert it to radians, and send `K i <1000 / angle_in_rad>`. Write the value down: it will go into `config.h`.
  </Step>
  <Step title="Move with real angles">
    Only now use `J i q` or `P …` with real angles, or drive the hand from the [digital twin](/docs/simulation-setup#the-digital-twin).
  </Step>
</Steps>

### Calibrating a joint

Why the last steps matter: the motor turns a spool, but how much the *joint* turns for each motor step depends on the tendon's moment arm at that joint, which hasn't been measured. Until each joint is calibrated, the firmware assumes 1:1 (about 648.7 half-steps per radian). A guided calibration tool is planned.

## Coming next: smart servos

The planned upgrade replaces the steppers with **Feetech SCS0009** smart servos on a single serial bus (through an FE-URT-1 adapter). They report their own position, so manual homing goes away, and one shared data line frees up most of the pins, including the tricky ones above. The firmware is already structured for this: joint code talks to a `MotorDriver` interface, and a servo driver can replace the stepper driver without touching the rest.

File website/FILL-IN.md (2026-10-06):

# Fill in later

Things removed or left out of the public site so it reads as finished. Add them back when you have the material. Paths are relative to `website/`.

## Gallery (`content/data/gallery.json`, intro in `content/pages/gallery.mdx`)
Six items were dropped because they only had a placeholder picture. Add each back with a real file in `media/` (see `media/README.md`), then an entry with `src`, `alt`, `caption`, `width`, `height` (videos also `poster`):
- Close-up of the back of the index finger showing the tendon loops (landscape 16:10).
- Video, 5-10 s, 16:9: the index finger closing and opening smoothly (plus a poster frame). Needs the first power-on.
- Screenshot of `uv run python sim/view.py` with the hand in a pinch pose and the Control sliders visible (landscape 16:10).
- Video, 10-15 s, portrait 4:5: laptop running `sim/twin.py --port auto` next to the real hand, joints following the sliders (plus poster).
- Photo of the real hand holding a pinch pose, ideally holding a small object (portrait 4:5).
- Screenshot of the Fusion 360 thumb and index design on a clean background, maybe a section view through a joint (landscape 16:10).

## Build log (`content/log/*.mdx`)
- Covers: the firmware post uses the electronics photo; the MuJoCo post and the Python post use two teleop screenshots as stand-ins. Replace the `cover:` line with a better picture when you have one (a screenshot of the model in the MuJoCo viewer; `sim/twin.py --fake` showing the viewer and terminal).
- Removed figures: MuJoCo viewer screenshot in `2026-09-26-first-mujoco-model.mdx` (after "the tests fail if the committed model is out of date") and the digital twin screenshot in `2026-09-27-python-library-digital-twin.mdx` (after the `--fake` paragraph).

## Hardware page (`content/pages/hardware.mdx`)
- Links to each STL/3MF and to the .f3d/STEP files, once committed (removed hidden TODO).
- Print settings: the "Tested value" column was removed. Add it back with the settings actually used, per part (hidden TODO removed).
- Wiring diagram: the placeholder diagram was replaced by one sentence. Add a real diagram of the ESP32-S3, 8 ULN2003 boards and the 5 V supply.
- The "What is in the repository today" callout should change once print-ready files are in `hardware/print/`.

## Bill of materials (`content/data/bom.json`)
The TODO cells were replaced with rough, honest wording. Replace with measured values:
- PLA/PETG filament: grams per hand, brand and colour (now "a few hundred grams").
- Tendon line: length per joint (now "a few metres per hand"; 0.4 mm fishing line).
- TPU filament: amount per pad and shore hardness (now "a few grams", "flexible filament").
- Servo power supply: now "5 to 6 V, at least 15 A" from the V1 design; confirm the part you buy (e.g. Mean Well LRS-100-5).
- Prices: no prices anywhere yet.

## Docs
- `content/docs/assembly.mdx`: five photo/diagram placeholders removed. Add: all printed parts laid out and labelled; assembled index finger straight and bent; motor bank labelled M1-M8; tendon routing diagram for one joint (material, length, how to tie off); wiring photo and diagram.
- `content/docs/build-guide.mdx`: add the STL/3MF files with per-part print settings (Printing section), and tendon material, diameter, routing and pre-tension (Tendons section).
- `content/docs/faq.mdx`: add a cost estimate in "What does it cost to build?" once the BOM has prices.

## Contribute page (`content/pages/contribute.mdx`)
- Add `CONTRIBUTING.md` to the repository (code style, tests, commit messages) and link it.
- Adopt a code of conduct (e.g. Contributor Covenant), add `CODE_OF_CONDUCT.md` and link it.

## Software page (`content/pages/software.mdx`)
- Add a screenshot or short video of the digital twin (the real finger following a slider in MuJoCo).

## Site-wide
- Domain: once you have one, set `NEXT_PUBLIC_SITE_URL` in Vercel (and `NEXT_PUBLIC_DOCS_URL` for the docs subdomain). See `DEPLOY.md`.

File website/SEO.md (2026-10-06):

# SEO and AI discoverability

How the Tendra Hand site is set up to be found by search engines and cited by AI assistants (ChatGPT, Claude, Perplexity, Gemini), and what you still need to do off-site.

## What is built in

- **Metadata on every page:** unique title and description, canonical URL, Open Graph and Twitter cards. Docs pages use the docs host (`docs.<domain>`) as canonical once `NEXT_PUBLIC_DOCS_URL` is set.
- **Structured data (JSON-LD)** in `src/components/seo/`:
  - every page: Organization, WebSite and SoftwareSourceCode (links the GitHub repo and the three licenses);
  - docs and build-log posts: TechArticle + BreadcrumbList; the FAQ also gets FAQPage (built from `content/docs/faq.mdx`, so every `## Question` becomes a Q&A);
  - `/gallery`: ImageGallery; `/docs` and `/docs/log`: CollectionPage; `/journey`, `/contribute`: WebPage.
- **`/llms.txt`** (llmstxt.org): a short Markdown map with key facts and a link plus one-line description for every page, doc and log post. **`/llms-full.txt`**: all docs, reference pages, the roadmap and log posts as one Markdown file. Both are generated at build time from `content/`. The "Key facts" list is in `src/components/seo/llms.ts` (`KEY_FACTS`): update it when the hardware or status changes.
- **robots.txt allows AI crawlers**, `sitemap.xml` lists every public page.
- All text on the home and project pages is server-rendered HTML, so crawlers that do not run JavaScript still read it.

## Do these after the domain exists

1. Set `NEXT_PUBLIC_SITE_URL` (and `NEXT_PUBLIC_DOCS_URL` for the docs host) in Vercel, then redeploy. Until then canonical URLs and the sitemap point at the Vercel address.
2. **Google Search Console:** add the domain, verify with the DNS record, submit `https://<domain>/sitemap.xml`. Request indexing for the home page.
3. **Bing Webmaster Tools:** add the site (you can import it from Search Console), submit the sitemap. Bing feeds ChatGPT search and Copilot, so this matters for AI answers.
4. **GitHub repo:** fill in the description (one sentence, like the site's), the website link, and topics such as `robotic-hand`, `tendon-driven`, `open-source-hardware`, `robotics`, `mujoco`, `3d-printing`, `esp32`, `dexterous-manipulation`. Put a short README intro with the same facts as `llms.txt`.
5. **Share it where makers and AI crawlers look:** a Hackaday.io project page, r/robotics and r/3Dprinting, Hacker News ("Show HN: Tendra Hand, an open-source tendon-driven robotic hand"), and a write-up on Instructables or Printables. Each is a backlink and a place AI tools learn from.
6. **Later:** a Wikidata entry once there are independent sources (articles, videos), and a YouTube video of the hand moving with the site link in the description.

## Keep it consistent

- Always write the name as **Tendra Hand** (two words, capital T and H), the same in the repo, the site, social posts and videos. Assistants cite what they can match across sources.
- Say the same facts everywhere: open-source, tendon-driven, 3D-printed, same joints as a human hand, V0 = thumb + index (8 joints), V1 = five fingers (20 joints, 16 servos), licenses Apache-2.0 / CERN-OHL-S-2.0 / CC BY 4.0.
- **Name clash:** an unrelated open-source project "Tendra H1" (github.com/aymankhayat/tendra-h1-robotic-hand) uses a similar name. `llms.txt` says they are different. Revisit the name before registering a company or trademark (see `CLAUDE.md`).
- Date your pages: `updated:` in doc frontmatter becomes `dateModified` in the schema.

## Check it

- Rich results: https://search.google.com/test/rich-results (paste a live URL).
- Schema validity: https://validator.schema.org.
- Ask ChatGPT, Claude and Perplexity "What is Tendra Hand?" a few weeks after launch and note what they get wrong; fix it in `llms.txt` and the home page text.

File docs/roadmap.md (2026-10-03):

# Tendra Hand — Roadmap

## The ultimate goal

**A robot that can do what humans can do, and do it just as well:** cook a meal, fold laundry, load a dishwasher, tidy a room, use everyday tools. Not only picking things up, but *understanding* a task (what needs to happen, in what order, and why) and carrying it out with human-level skill.

**The hand is the focus.** Almost every useful thing people do goes through their hands, and dexterous hands are the hardest unsolved part of general-purpose robots. So we start there: a hand as capable as a human one, then the intelligence to use it, then the body to take it into real homes.

The path, from the bottom up:

1. **Hand** (Phases 0–3): the V0 prototype, then **Tendra Hand V1**, a human-like hand (20 joints on 16 servos) that moves smoothly and precisely.
2. **Senses** (Phase 4): touch and vision, so the hand knows what it's holding and how hard.
3. **Skills** (Phases 5–6): learned dexterous skills — grasping, in-hand manipulation, tool use.
4. **Understanding** (Phase 7): AI that turns an instruction like "make a sandwich" into a plan and the right skills.
5. **Body** (Phase 8): the hand on an arm and then a mobile robot, doing real chores in real homes.

Each phase has a clear **"done when"** so progress is measurable. Phases can overlap. The open-source track runs the whole time.

---

## Phase 0: Foundation ✅ in progress
Set up the project so everything after it is easy.

- [x] Project structure, CLAUDE.md, READMEs
- [x] Inspect the Fusion URDF export and document its problems
- [x] Git + public GitHub repo, licenses
- [x] Python environment (uv, Python 3.12, MuJoCo)
- [x] Converter: Fusion export → MuJoCo MJCF (PLA masses, valid inertias, joint names, closing-positive)
- [x] MuJoCo viewer with a slider per joint
- [x] Owner checks the sim motions against the real hand (confirmed 2026-09-26)

**Done when:** the hand model loads in MuJoCo with correct joint limits and can be posed with sliders.

## Phase 1: V0 prototype — thumb + index on steppers
Just a start: make the 8-joint prototype move cleanly and control it from the PC, to learn the basics before V1.

- [x] Firmware skeleton in PlatformIO; all motor pins LOW at boot, PSRAM disabled
- [x] Motor **hardware abstraction layer** (`MotorDriver` interface) + `Uln2003Stepper`
- [x] Smooth motion: acceleration/deceleration ramps, non-blocking stepping of all 8 motors at once (tested on PC; hardware test pending)
- [x] Coil release when idle (power budget: 5 V / 2 A)
- [x] PC ↔ ESP32 serial protocol, firmware side (text v0.1)
- [x] PC-side serial client (`tendra.RealHand`, tested against a software ESP32)
- [x] Python `Hand` API with `RealHand` and `SimHand` backends
- [ ] Per-joint calibration: steps per radian, direction, limits
- [x] **Digital twin** software: control the real hand from the MuJoCo sliders (`sim/twin.py`)
- [ ] Hardware bring-up: first power-on checklist, direction check per motor
- [ ] Basic motions: open/close, pinch, point

**Done when:** all 8 joints move smoothly (no jerks, no missed steps) through their full range, and the sim and the real hand match within a few degrees.

## Phase 2: Tendra Hand V1 — the first full hand
Five fingers, 20 joints (4-DOF thumb) on 16 Feetech SCS0009 smart servos (position feedback, no manual homing, one shared bus); each finger's fingertip joint follows its middle joint (DIP = 0.75 × PIP) through a rigid linkage bar, with no servo of its own. This is the first real Tendra Hand.

- [x] Middle, ring and little fingers (reuse the index design, with sizes scaled to human proportions) — designed in Fusion "Tendra Hand V1" (2026-09-28)
- [x] Thumb base reworked for PTFE-sheathed tendons (hollow pivot); 5th thumb DOF tried and removed again (owner, 2026-09-29)
- [x] Actuator packaging (forearm), tendon routing through the wrist: one channel per strand, tested (`hardware/cad/tendon_router.py`)
- [x] Full-hand MJCF (20 joints, 16 servos, 36 tendons: 32 servo strands + 4 DIP linkage bars): `sim/models/tendra_hand_v1.xml`
- [x] `Scs0009Servo` driver behind the same HAL (joint code unchanged), firmware env `hand_v1_servo`
- [ ] Full-hand electronics and power budget on the servo bus (plan in `research/experiments/2026-09-28-full-hand/research.md`)
- [ ] Wire the servo bus: ESP32 UART → FE-URT-1 → daisy-chained SCS0009s; assign IDs 1–16
- [ ] Mechanical adapters: servo mounts and tendon spools
- [ ] Test channels and PTFE fit on a printed section first, then print and assemble V1
- [ ] Read back position, load and temperature on the real hand
- [ ] **Digital twin mirror:** sim follows the *measured* joint positions (real → sim), not only the commanded ones
- [ ] Compare steppers (V0) vs. servos (V1): speed, precision, force, noise → research log

**Done when:** all five fingers are actuated and controllable from the PC with the same Python API, and the twin shows measured positions live.

## Phase 3: Mechanics, tendons and system identification
Make V1 robust and the simulation realistic.

- [ ] Tendon friction and pre-tension study on the real hand; tune the MuJoCo tendons
- [ ] Convex decomposition of the palm (and other concave parts) for accurate contact
- [ ] TPU fingertip pads
- [ ] **System identification:** measure real speed, friction and backlash, and tune the sim to match
- [ ] Measure the real mass of printed parts and update the model

**Done when:** simulated and real joint motions match closely under the same commands, and the hand survives long test runs.

## Phase 4: Sensing
- [ ] Fingertip touch/force sensing
- [ ] Camera (hand-eye setup) for vision
- [ ] Sensor data streamed into the Python API and the sim

## Phase 5: AI control
Detailed AI research plan for Phases 5–8 (architecture, stages, maths, resources, ideas): `research/ai/`.

- [ ] **Teleoperation:** control the hand by moving your own hand in front of a webcam (hand tracking). Great for demos and for collecting data. Software done for the sim (`sim/teleop.py`, 2026-09-28); live test and real hand pending.
- [ ] Imitation learning from recorded demonstrations
- [ ] Reinforcement learning in MuJoCo with domain randomization, then **sim-to-real** transfer (on cloud GPUs, since the dev laptop has no NVIDIA GPU)
- [ ] Optional: move to Isaac Sim/Lab for large-scale training

## Phase 6: Vision-based grasping and complex tasks
- [ ] Detect objects with the camera and plan grasps
- [ ] Complex tasks: in-hand rotation, tool use, handling everyday objects
- [ ] Publish benchmarks and results

**Done when:** the hand reliably does a set of benchmark tasks with everyday objects (e.g. open a jar, use scissors, rotate a cube in hand).

## Phase 7: Task understanding
Go from "do this motion" to "do this job".

- [ ] Vision-language-action (VLA) model: camera image + spoken or written instruction → hand actions
- [ ] Task planning: break a long task ("make a sandwich") into steps and pick a learned skill for each
- [ ] Recover from mistakes: notice when a step failed (dropped object, slipped grip) and try again
- [ ] Learn new tasks from a few human demonstrations
- [ ] Open dataset of hand demonstrations for household tasks

**Done when:** given a plain-language instruction, the hand plans and completes multi-step tabletop tasks it hasn't been scripted for.

## Phase 8: Arm, body and real chores
Take the hand out of the lab and into a home.

- [ ] First body: a **bimanual station**: two 7-DOF arms with two Tendra hands on a fixed pole (optional linear lift), head + wrist cameras (`research/ai/vision.md`)
- [ ] Mount the hand on a robot arm (wrist with 2–3 DOF), two hands for bimanual tasks
  - [x] Sim: one right arm = OpenArm v2 shoulder + elbow (J1–J4, its J5 motor turns our forearm), Tendra forearm, 2-way wrist, V1 hand (`tendra.arm`, 2026-10-02)
  - [x] Sim: the grasp scene and RL env run on the arm only (the floating hand is removed; `train_grasp.py --hands`; IK turns the wrist target into joint targets; 2026-10-02)
  - [x] Sim: bimanual pedestal: the left arm and a mirrored left hand (`hardware/cad/mirror_export.py`, `convert_v1.py --side left`), one policy drives either hand (2026-10-02)
  - [ ] Sim: train a real policy on both arms (one hand each, then one model for both hands), port the GPU path and the webcam teleop to the arm scene
  - [ ] Hardware: wrist gimbal with a hollow centre for the PTFE sheaths, wrist actuators, slimmer forearm; own arm design based on OpenArm
- [ ] Kitchen tasks: cut, stir, pour, crack an egg, cook a simple meal
- [ ] Household chores: fold laundry, load a dishwasher, tidy up
- [ ] Mobile base / humanoid body to move between rooms
- [ ] Safety around people: force limits, soft contact, stop on unexpected touch

**Done when:** the robot does everyday chores in a real home as well as a person.

---

## Open-source track (all phases)
- [ ] Public GitHub repo, licenses, contribution guide
- [ ] Project website with downloads (CAD, STL, firmware, models), docs and research
- [ ] Build guide + bill of materials (BOM) with costs
- [ ] Tagged releases for every hardware/software milestone
- [ ] Demo videos

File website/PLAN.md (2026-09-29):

# Website build plan (v1)

> **Status 2026-09-27:** waves 0–3 done. All 26 routes build statically; tsc/eslint clean; Lighthouse 90+ mobile / 100 desktop on every route; axe clean (light + dark). Ownership rules below applied while the agents ran in parallel; they're kept as the map of who built what.

The lead agent owns this file. Agents read it before starting and report back
instead of editing files they don't own.

## Stack

Next.js 16 (App Router, Turbopack) · TypeScript · Tailwind v4 · React Three Fiber 9 + drei 10 · GSAP 3 + ScrollTrigger · Lenis · MDX via `@next/mdx` (frontmatter, GFM, heading ids, Shiki dual-theme highlighting are already wired in `next.config.ts`).

**Design system = `assets/css/*`** (tokens, base, components). It is imported by `src/app/globals.css`; Tailwind utilities map to the tokens (`bg-bg-alt`, `text-text-muted`, `text-accent-ink`, `rounded-lg`, `shadow-md`, `text-h2`, …). Read `styleguide/index.html` and `README.md` first.

Rules from the design system (non-negotiable):
- Light default, dark opt-in (`<html data-theme="dark">`). Colours **only** through tokens — no hex values in components (exception: three.js materials must read tokens at runtime via `getComputedStyle`).
- Blue (`--accent`) **only for clickable things** (plus the 3D rim light / tendon glow, which is the project's signature). One primary button per view. No orange.
- Clean, open, friendly, Apple-like. Lots of white space. Pill buttons, rounded cards, soft shadows. **Not** a dark "robotic/nerdy" look.
- Plain words for a general audience.
- Motion respects `prefers-reduced-motion`; content is readable without JS.
- Use existing design-system classes (`btn btn--primary`, `card`, `tag`, `section`, `section--alt`, `section-head`, `spec`, `stat`, `panel`, `code`, `kicker`, `lead`, `caption`, `display`, `auto-grid`, `container`) before inventing new styles.
- ⚠️ The design system's grid helper is `.auto-grid` (renamed from `.grid` so it doesn't clash with Tailwind's `grid`). `.container` is pinned in `globals.css`.

## File structure

```
website/
  PLAN.md                    this file
  assets/ styleguide/        design system (source of truth; copied to public/ by scripts/sync-styleguide.mjs)
  content/                   ALL editable text lives here
    site.json                name, url, GitHub, nav, footer            (lead)
    home.json                homepage copy + story sections + stats + CTA
    roadmap.json             roadmap phases (home + project page)
    pages/<page>.mdx         project, hardware, software, gallery, log, contribute (frontmatter + body)
    data/bom.json            bill of materials
    data/gallery.json        gallery items
    log/<yyyy-mm-dd-slug>.mdx build-log posts
    docs/**                  docs pages (+ docs nav file)
  public/models/             hand.glb goes here (README explains the node naming)
  public/images/placeholders/ labelled placeholder SVGs
  src/
    app/                     routes
      layout.tsx globals.css (lead)
      page.tsx               home
      project/ hardware/ software/ gallery/ contribute/ log/ log/[slug]/
      docs/ docs/[...slug]/
      dev/hand/              "hand lab": sliders for every HandState field (noindex, not in sitemap)
      template.tsx           route transition
      sitemap.ts robots.ts opengraph-image.tsx not-found.tsx
    components/
      ui/                    shared primitives (lead): Reveal, CountUp, Tag/StatusBadge, SectionHead, Placeholder, CopyButton
      layout/                Nav, Footer, ThemeToggle, MobileMenu, ScrollProgress, SmoothScroll
      three/                 R3F canvas, placeholder hand, GLB loader, lights, tendons, labels
      home/                  homepage sections + scroll story + electronics diagram + roadmap timeline
      pages/                 page-specific components (BomTable, Gallery grid + lightbox, LogCard, …)
      docs/                  sidebar, search, TOC, prev/next
      mdx/                   components usable in every .mdx file (index.tsx registers them)
    lib/
      handState.ts           ★ scroll ↔ 3D contract (lead)
      mdx.ts                 listMdxSlugs(), loadMdx() (lead)
      site.ts theme.ts       (lead)
      scroll/                GSAP/Lenis setup + homepage timeline
      docs.ts                docs tree, search index
    styles/prose.css         long-form MDX styles
```

## Content formats (Content Agent writes, everyone else reads)

- `content/pages/<page>.mdx` frontmatter: `title`, `kicker`, `lead`, `description` (SEO, ≤160 chars). Body is MDX.
- `content/log/<yyyy-mm-dd-slug>.mdx` frontmatter: `title`, `date` (YYYY-MM-DD), `summary`, `cover` (path, optional), `tags` (string[]). Newest first by `date`.
- `content/home.json`:
  ```jsonc
  {
    "hero": { "kicker": "", "title": "", "lead": "", "primaryCta": { "label": "", "href": "" }, "secondaryCta": { "label": "", "href": "" } },
    "story": [ // exactly these ids, in this order
      { "id": "intro" | "tendons" | "joints" | "exploded" | "electronics", "kicker": "", "title": "", "body": ["paragraph", "..."], "points": ["optional short bullet"] }
    ],
    "diagram": { "nodes": [ { "id": "pc" | "esp32" | "motors", "label": "", "detail": "" } ], "caption": "" },
    "stats": { "kicker": "", "title": "", "items": [ { "value": 8, "unit": "", "label": "" } ] },
    "cta": { "title": "", "lead": "", "label": "", "href": "" }
  }
  ```
- `content/roadmap.json`: `{ "kicker", "title", "lead", "phases": [ { "id", "title", "summary", "status": "done" | "in-progress" | "planned", "items": [string] } ] }`
- `content/data/bom.json`: `{ "updated": "YYYY-MM-DD", "groups": [ { "name", "items": [ { "part", "qty", "spec", "notes", "link"? , "status": "have" | "planned" } ] } ] }`
- `content/data/gallery.json`: `{ "items": [ { "type": "image" | "video", "src", "poster"?, "alt", "caption", "width", "height", "todo" } ] }` — `todo` says what real photo/video should replace the placeholder.
- Real media: files in the repo's `media/` folder (see `media/README.md`, described in `media/catalog.json`), copied to `public/media/` by `scripts/sync-styleguide.mjs` and referenced as `/media/photos/…`. Replace a placeholder by pointing `src` there and removing its `todo`.
- Placeholders: SVGs in `public/images/placeholders/` with the subject written on them. Every placeholder in MDX/JSON/components has a `TODO:` marker (JSX comment, MDX comment `{/* TODO: … */}`, or a `todo` field).

### MDX components (available in every .mdx without import)

Built by the Docs Agent (wave 1) unless noted; registered in `src/components/mdx/index.tsx`:

| Component | Props |
|---|---|
| `<Callout type="note" \| "tip" \| "warning" title?>` | children |
| `<Figure src alt caption? width? height?>` | image with caption (next/image) |
| `<Video src poster? caption?>` | muted, playsinline, controls; lazy |
| `<Placeholder label ratio?>` | wraps `ui/Placeholder` |
| `<StatusBadge status="done" \| "in-progress" \| "planned">` | wraps `ui/StatusBadge` |
| `<CardGrid>` + `<Card title href? kicker?>` | children = body text |
| `<Steps>` + `<Step title>` | numbered assembly steps |
| `pre`/`code` override | Shiki block with filename bar + copy button (`title` from the code fence meta if possible) |
| `<BomTable />` | (Pages Agent, wave 2) renders `data/bom.json` |
| `<Roadmap />` | (Pages Agent, wave 2) renders `roadmap.json` via the home RoadmapTimeline |

## Scroll-animation plan (homepage)

The homepage is one long scroll story. A **sticky canvas** holds the hand; the
GSAP timeline, scrubbed by ScrollTrigger (with Lenis smoothing), tweens the
plain numbers in `src/lib/handState.ts`. The R3F scene reads them every frame.

| # | Section | Layout (desktop ≥ 1024px) | `handState` targets |
|---|---|---|---|
| 0 | **Hero** | Canvas full-width, centred behind/under the headline | `idle 1, rim 1, rotation 0, zoom 1` — slow idle spin + breathing, accent rim light |
| 1 | **Intro** ("every joint, its own motor") | Canvas slides to the right half; text column scrolls on the left | `idle → 0.2, rim → 0.6, rotation.y → -0.5` (three-quarter palm view) |
| 2 | **Tendons** | right | `rotation.y → π` (back of the hand), `tendons 0 → 1` (glowing lines along the back of each finger), `rim → 0.3` |
| 3 | **Joints / DOF** | right | `rotation.y → -0.35, rotation.x → 0.25`, `tendons → 0`; joints bend **one by one** (index MCP → PIP → DIP, then thumb CMC → MCP → IP), `labels → 1` (MCP/PIP/DIP pills pop at each joint as it bends), then all return to 0 |
| 4 | **Exploded view** | right (may switch to left once if it reads better) | `labels → 0`; `explode 0 → 1` over the first half, hold, `1 → 0` over the second half; slow `rotation.y` drift |
| 5 | **Electronics** | right | `wireframe 0 → 1`, `zoom → 0.85`; HTML/SVG diagram **PC → ESP32-S3 → motors** fades in over/next to the canvas (real text, not in WebGL) |
| 6 | Stats → Roadmap → CTA | canvas un-pins and scrolls away; rendering pauses off-screen | — |

Text sections: each story section is ≥ 100vh tall on desktop so there's time for the animation; headings/paragraphs reveal as they enter.

**Mobile (< 768px):** the canvas is sticky at the top (~42svh) and text scrolls underneath (never side by side). Simpler animation: no one-by-one joint sequence (all bend together), no rotation drift, labels only for the index finger.
**Tablet (768–1023px):** same as mobile but a larger canvas.
**`prefers-reduced-motion`:** no Lenis, no scrubbing. A single static render (the three-quarter pose) at the top of the story, then the sections as normal content, the diagram shown statically.
**No JS:** all text is server-rendered; the canvas area shows a placeholder.

### 3D component API (3D Agent delivers, Scroll Agent consumes)

- `src/components/three/HandCanvas.tsx` — `export default function HandCanvas(props: { state?: HandState; mode?: "animated" | "static"; className?: string })`. Client-only; the homepage loads it with `next/dynamic(..., { ssr: false })`. It fills its parent box. Internally: `dpr={[1, 1.75]}`, pauses rendering when off-screen (IntersectionObserver → `frameloop="never"`) and when the tab is hidden, `mode="static"` renders one frame (`frameloop="demand"`). Reads `--accent`, `--text`, `--bg` from CSS at runtime and re-reads on theme change (`useTheme()` from `src/lib/theme.ts`).
- `src/components/three/model.ts` — **the one line to swap in the real model**: `export const HAND_MODEL_URL: string | null = null; // TODO: set to "/models/hand.glb"`. `null` = procedural placeholder hand.
- GLB convention (documented in `public/models/README.md`): a node named after each `JointId` (e.g. `index_pip`) whose origin is the joint pivot and whose local X axis is the flexion axis. If those nodes exist they're animated; otherwise the whole model only rotates (fallback). Optional `tendon_*` curve nodes; otherwise tendons are generated from joint positions.
- Placeholder hand: low-poly five-finger hand from primitives (rounded boxes/capsules), PLA-white material, correct joint hierarchy for all 17 `JointId`s, dorsal tendon paths, joint label anchors.

## Agents, waves and file ownership

An agent edits **only** files it owns. Shared files are owned by the lead; ask the lead (report it) instead of editing. No `git commit`, no `git push`.

| Wave | Agent | Owns | Done when |
|---|---|---|---|
| 0 | **Lead** | `package.json`, configs, `src/app/layout.tsx`, `src/app/globals.css`, `src/lib/{handState,mdx,site,theme}.ts`, `src/components/ui/**`, `content/site.json`, `PLAN.md` | scaffold builds ✅ |
| 1 | **Content** | `content/home.json`, `content/roadmap.json`, `content/pages/**`, `content/data/**`, `content/log/**`, `public/images/placeholders/**` | all files match the formats above; facts match the repo; every placeholder has a TODO |
| 1 | **3D** | `src/components/three/**`, `src/app/dev/hand/**`, `public/models/**` | `/dev/hand` shows the placeholder hand; every HandState field visibly works via sliders; tsc + eslint clean |
| 1 | **Docs** | `src/app/docs/**`, `src/components/docs/**`, `src/components/mdx/**`, `src/lib/docs.ts`, `src/styles/prose.css`, `content/docs/**` | `/docs` with sidebar, search, TOC, prev/next and starter pages; all MDX components in the table above (except wave-2 ones) work |
| 2 | **Scroll** | `src/app/page.tsx`, `src/components/home/**`, `src/lib/scroll/**`, `src/components/layout/SmoothScroll.tsx` | homepage story works on desktop, mobile and reduced motion; stats, roadmap, CTA |
| 2 | **Pages** | `src/app/{project,hardware,software,gallery,contribute,log}/**`, `src/app/{template,not-found,sitemap,robots,opengraph-image}.*`, `src/components/pages/**`, `src/components/layout/**` (not SmoothScroll), and takes over `src/components/mdx/index.tsx` | all pages render from `content/`; mobile menu; scroll progress bar; route transitions; OG images; sitemap |
| 3 | Design review → Accessibility → Performance → Code review | (sequential, so fixes never collide) | see `.claude/agents/*.md` |

### Working rules for build agents

- **Parallel builds:** never use the default `.next` folder. Use your own dist dir and port:
  `NEXT_DIST_DIR=.next-<agent> npx next dev -p <port>` — ports: 3D 3101, Docs 3102, Scroll 3103, Pages 3104, reviewers 3105. Always stop your server when done (`netstat -ano | grep :<port>` → `taskkill //PID <pid> //F //T`).
- **See your work:** `npx -y playwright@1 screenshot --channel chrome --viewport-size=1440,900 --wait-for-timeout=4000 http://localhost:<port>/<path> <scratchpad>/<name>.png`, then open the PNG with the Read tool. Also try `--viewport-size=390,844` for mobile. (`--full-page` for long pages.)
- **Checks before reporting done:** `npx tsc --noEmit` and `npx eslint <your files>` must be clean for your files.
- No new npm dependencies without asking the lead, except the Docs Agent may add **one** small search library if really needed.
- Code style: TypeScript strict, function components, server components by default (`"use client"` only where needed), comment density like the existing files, no dead code. Mark every placeholder with `TODO:`.
- Report back: what you built (files), how you verified it (screenshots taken, checks run), open problems, anything you needed from another agent.

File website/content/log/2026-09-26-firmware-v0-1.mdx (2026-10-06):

---
title: "Firmware v0.1: smooth motion for 8 steppers"
date: "2026-09-26"
summary: "The first firmware for the ESP32-S3: gentle speed-up and slow-down, all 8 motors moving at once, and a simple text command language. Tested on the computer, not yet on the hand."
cover: /media/photos/2026-09-29-v0-electronics-overview.jpg
tags: ["firmware", "esp32", "motors"]
---

With the simulation working, the next job was the firmware: the code on the ESP32-S3 microcontroller that turns joint angles into motor motion.

## Smooth, not jerky

A stepper motor that starts at full speed jerks, and can skip steps. So every move follows a trapezoid: speed up gently, cruise, then slow down gently before the target. If a new target arrives halfway through, the motor brakes and turns around smoothly instead of stopping dead. All 8 motors run at the same time without waiting for each other.

Because the hand wasn't finished, I tested the motion code on the laptop instead. A 4000-step move ends exactly on target in 5.506 seconds, against an ideal of 5.5.

## Careful with power

Each 28BYJ-48 motor draws around 200 to 250 mA per coil while it's switched on, and the motors share a 5 V / 2 A supply. So a motor switches off after 1 second of standing still. Startup is careful too: every motor pin goes low first thing, and nothing moves until the computer asks.

## Talking to it

The computer and the ESP32 talk in short lines of text over USB. Angles are always in radians, and positive means closing the hand. This sets joint 2 (the index finger's middle joint) to 0.8 radians, then asks for the status of all joints:

```text title="Serial monitor"
J 2 0.8
S
```

Plain text means anyone can type commands by hand while testing.

## Ready for servos

All the motor code sits behind one small interface, and the joint logic never touches a pin directly. When the Feetech SCS0009 smart servos replace the steppers, only a new driver has to be written.

<Figure src="/media/photos/2026-09-29-v0-electronics-overview.jpg" alt="The ESP32-S3 on a breadboard, wired to the ULN2003 stepper driver boards." caption="The ESP32-S3 and the ULN2003 driver boards." width={1125} height={2000} />

## Not done yet

None of this has driven a real motor so far. The next hardware steps are a first power-on, one motor at a time, checking that each one turns the right way, and measuring how many steps each joint needs per radian.

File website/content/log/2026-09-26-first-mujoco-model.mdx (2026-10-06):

---
title: "From a CAD export to a working simulation"
date: "2026-09-26"
summary: "The Fusion 360 export said the hand weighed 821 g of steel. A small converter script turned it into a 131 g plastic hand that moves correctly in MuJoCo."
cover: /media/screenshots/2026-09-29-teleop-open-hand.png
tags: ["simulation", "mujoco", "cad"]
---

The first real step for Tendra Hand was getting the thumb and index finger into a simulator. A virtual copy lets me test ideas on a laptop before risking the real hardware, and later it's where the AI will learn.

## What the export got wrong

I designed the hand in Fusion 360 and exported it as a URDF, a standard file format that describes a robot's parts and joints. The joints came out right: 9 parts and 8 joints, with limits that match the real hand closely. The physics did not.

- **It was made of steel.** Fusion's default material gave a total of 821 g. At PLA density the same parts weigh about 131 g.
- **Some numbers were rounded away.** The values that describe how hard each part is to spin (its inertia) were rounded so far that two parts ended up physically impossible.
- **Two thumb joints had opposite directions,** so bending one was positive and bending the other was negative.

## Fix the script, not the file

Instead of editing the export by hand, I keep it untouched and wrote a converter that produces a clean MuJoCo model from it. It recomputes weights and inertias from the 3D meshes, gives every joint a readable name like `index_pip`, and makes sure a positive angle always means closing the hand. When the design changes, I export again and re-run one command:

```sh title="Terminal"
uv run python sim/convert.py && uv run pytest
```

The tests fail if the committed model is out of date, so it can't silently drift from the design.

## Not everything is perfect

The palm and the finger bases overlap where they join, and the thumb base "collides" with the palm at almost any rotation. That's an artifact of how the simulator simplifies the palm's shape, so for now those contacts are switched off. The proper fix is to split the palm into simpler pieces later.

With that, the simulated joints reach their targets within 0.8° and the simulation is stable. Then I moved every slider and compared it with the real hand: the motions match.

Next up: firmware for the ESP32-S3.

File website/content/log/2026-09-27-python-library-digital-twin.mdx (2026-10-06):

---
title: "One Python library for the real hand and its twin"
date: "2026-09-27"
summary: "The tendra Python package controls the simulated hand and the real hand with the same code, and digital twin v1 sends MuJoCo slider moves to the ESP32."
cover: /media/screenshots/2026-09-29-teleop-i-love-you-sign.png
tags: ["software", "python", "digital twin"]
---

The firmware can move motors. Now the computer needs a friendly way to tell it what to do.

## One interface, two hands

The new `tendra` Python package has one interface, `Hand`, with two versions behind it. `SimHand` drives the MuJoCo simulation, and `RealHand` talks to the ESP32 over USB. They share the same commands, so a script (or, later, an AI) written for one runs on the other.

```python title="example.py"
from tendra import SimHand

hand = SimHand()
hand.set_joint("index_pip", 0.8)   # radians, positive = closing
hand.wait()                        # let the simulation settle
print(hand.positions())
```

## Testing without hardware

The hand still isn't ready to power on, so I also wrote `FakeEsp32`, a small piece of software that pretends to be the ESP32 and answers the same text commands. `RealHand` can't tell the difference, which means the whole chain from Python to the command language can be tested today.

There are 20 tests so far. Some check that the joint names and limits agree in three places: the firmware, the Python code and the simulation model. If one of them changes and the others don't, a test fails.

## Digital twin v1

A digital twin is a virtual copy of the hand that stays in step with the real one. In this first version, you move a slider in the MuJoCo viewer and the new target goes to the hand. To keep the USB link calm, it only sends when something changes, and at most 20 times a second.

```sh title="Terminal"
uv run python sim/twin.py --fake
```

With `--fake`, the software ESP32 stands in for the hand. In a first test, the viewer, the simulation and the link all ran together and shut down cleanly.

## Something to tune

At rest, the simulated thumb sags about 1.2° under its own weight, because its simulated motor is a little soft. A real stepper holds firmly. That's a setting to tune once I can compare with the real hand.

Next: power on the real hand, check every motor's direction, and build a guided tool to calibrate each joint.

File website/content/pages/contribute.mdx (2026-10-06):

---
title: Contribute
kicker: Build it with us
lead: "Tendra Hand is open to everyone. Print a part, fix a bug, improve the simulation or ask a good question."
description: "How to help build Tendra Hand: print and test parts, improve the firmware, simulation or AI, write docs, or improve the design."
---

The project is early, which makes this a good time to join. Small help counts: a test print, a typo fix or a question that shows where the docs are unclear.

## Ways to help

<CardGrid min="18rem">
  <Card title="Print and test" kicker="Hardware">
    Print the parts, build a finger and tell us what broke, what was hard to assemble and which print settings worked for you.
  </Card>
  <Card title="Firmware" kicker="ESP32-S3, C++">
    Help with smooth motion, calibration and the driver for the Feetech SCS0009 smart servos.
  </Card>
  <Card title="Simulation and AI" kicker="Python, MuJoCo">
    Make the simulation more realistic (tendons, friction, contact), or help build teleoperation and learning-based control.
  </Card>
  <Card title="Docs and guides" kicker="Writing">
    Write build guides, explain things in plain words, add photos, or translate.
  </Card>
  <Card title="Mechanical design" kicker="CAD">
    Improve the fingers, the tendon routing and the thumb, which needs a fifth motion to fully match a human thumb.
  </Card>
</CardGrid>

## How to get started

<Steps>
  <Step title="Look around">
    Read the [project page](/project) and the [roadmap](/project#roadmap), and skim the [build log](/docs/log) to see where things stand.
  </Step>
  <Step title="Say hello">
    Open an [issue](https://github.com/Danielloka/tendra-hand/issues) for bugs and concrete ideas, or start a [discussion](https://github.com/Danielloka/tendra-hand/discussions) for questions and bigger ideas.
  </Step>
  <Step title="Send a change">
    Fork the repository, make your change and open a [pull request](https://github.com/Danielloka/tendra-hand/pulls). Keep it small and explain what it does and why.
  </Step>
</Steps>

To try the software without any hardware, clone the repository and run the simulation:

```sh title="Terminal"
git clone https://github.com/Danielloka/tendra-hand.git
cd tendra-hand
uv sync
uv run python sim/view.py
```

## Licenses

By contributing, you agree that your work is shared under the same licenses as the project:

| What | License |
|---|---|
| Code: firmware, Python, simulation, AI code and models | Apache-2.0 |
| Hardware: CAD, print files, electronics, robot model | CERN-OHL-S-2.0 |
| Docs, research and website text | CC BY 4.0 |

In short: anyone may use, build, change and sell Tendra Hand. If you share a changed hardware design, you share its design files under the same license. Please credit the project.

## Code of conduct

Be kind, be patient and assume good intent. Everyone here is learning, including the people who started it.

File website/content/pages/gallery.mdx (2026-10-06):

---
title: Gallery
kicker: Photos and videos
lead: "The hand as it takes shape: printed parts, tendons, electronics and the first moves."
description: "Photos and videos of the Tendra Hand prototype, from printed parts to the first motion tests and the digital twin."
---

Photos and screenshots from the build so far. More will follow as the prototype comes together.

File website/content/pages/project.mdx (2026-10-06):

---
title: The project
kicker: About Tendra Hand
lead: "Tendra Hand is an open-source, 3D-printed, tendon-driven robotic hand with the same joints as a human hand, as the first step toward a robot that can do what people do. Built step by step, and shared completely."
description: "Why Tendra Hand exists, the design decisions behind it, where the project stands today and where it is going next."
---

## The goal

The big goal is a robot that can do what people do, just as well: cook a meal, fold the laundry, load the dishwasher, use everyday tools. Not only pick things up, but understand a task and carry it out, step by step.

The hand is where it starts. Almost everything useful we do goes through our hands, and a hand that is as skilled as a human one is still the hardest part of building a helpful robot. So Tendra Hand first aims to do what your hand does: pinch a coin, turn a key, hold a pen. To get there, it needs the same joints as a human hand, and every one of them has to move on its own. Then come touch and vision, AI that learns skills and understands tasks, and finally an arm and a body to use it in a real home.
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

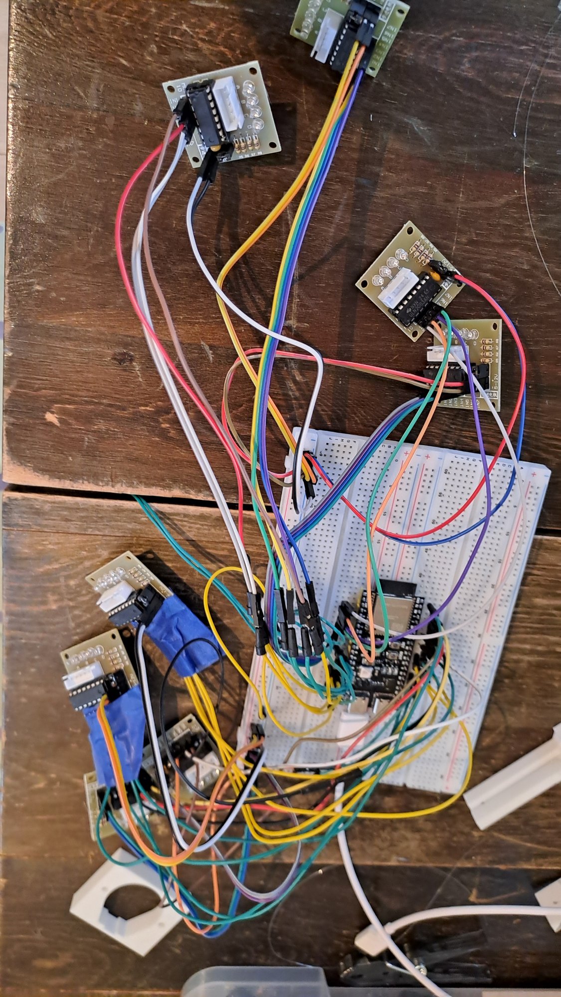
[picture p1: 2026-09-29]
media/photos/2026-09-29-v0-electronics-overview.jpg

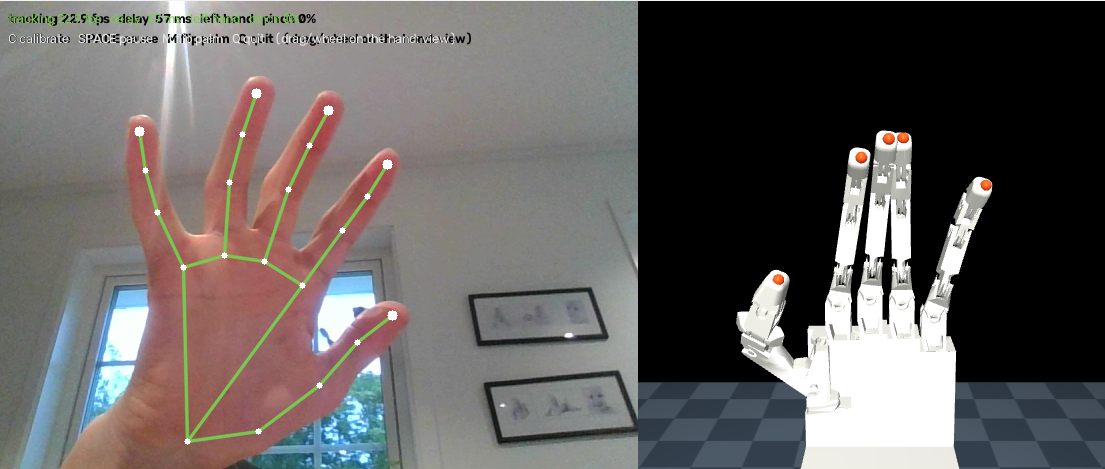
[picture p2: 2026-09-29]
media/screenshots/2026-09-29-teleop-open-hand.png

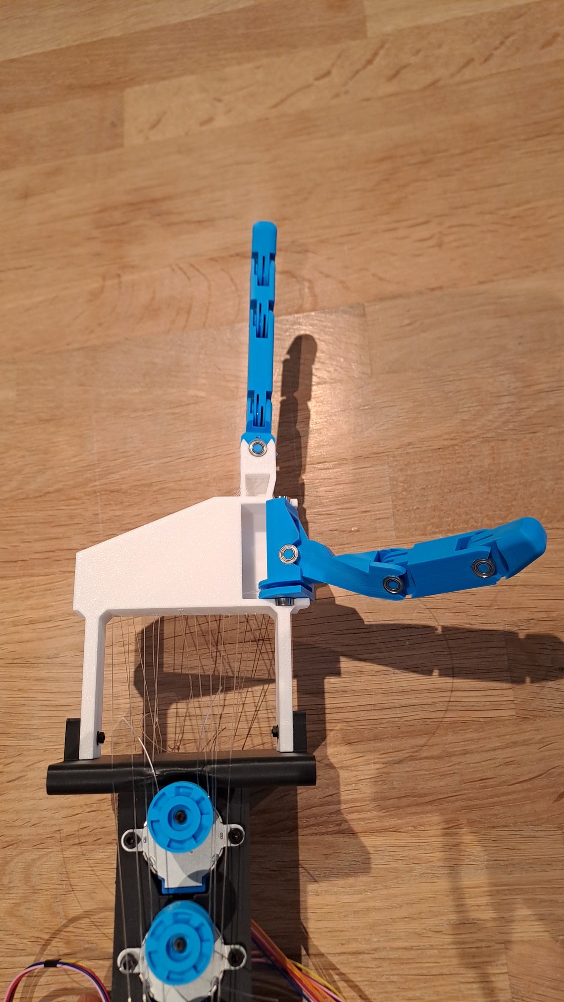
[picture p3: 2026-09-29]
media/photos/2026-09-29-v0-prototype-top-view.jpg

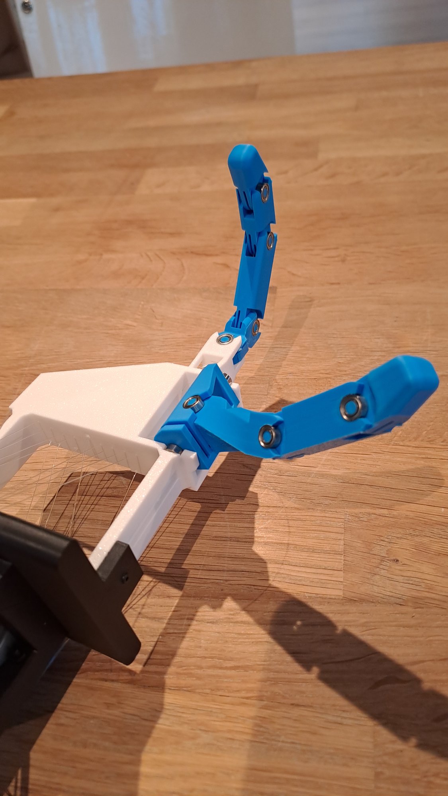
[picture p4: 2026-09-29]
media/photos/2026-09-29-v0-fingers-three-quarter.jpg

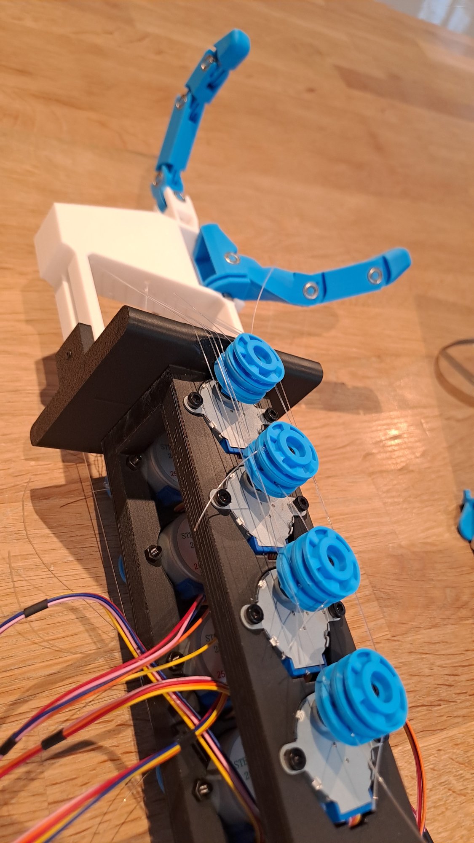
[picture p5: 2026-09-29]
media/photos/2026-09-29-v0-forearm-motors-spools.jpg

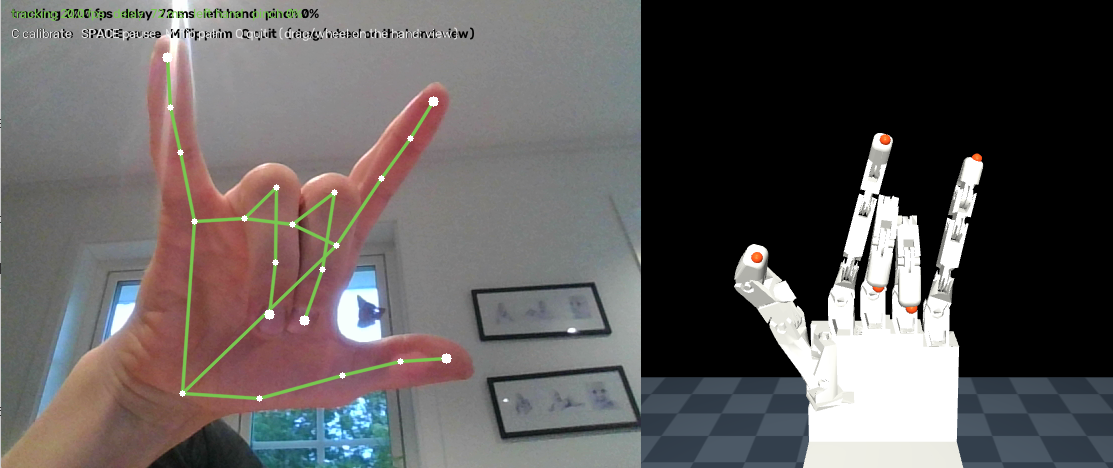
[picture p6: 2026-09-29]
media/screenshots/2026-09-29-teleop-i-love-you-sign.png

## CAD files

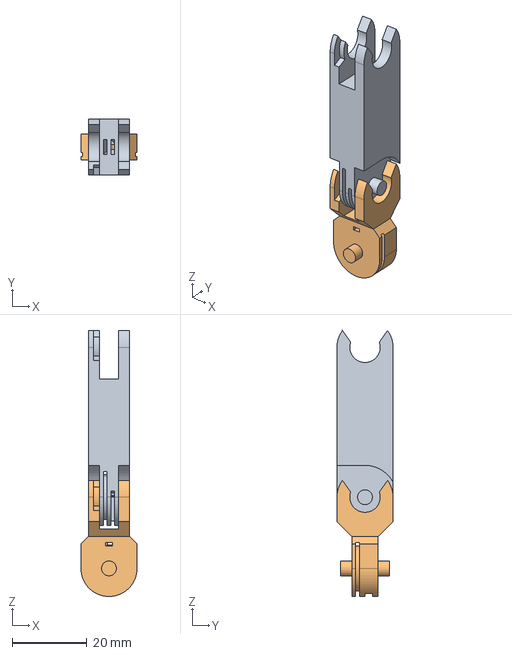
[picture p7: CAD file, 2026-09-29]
hardware/cad/Hand assebly.step
15.0 x 15.0 x 71.0 mm

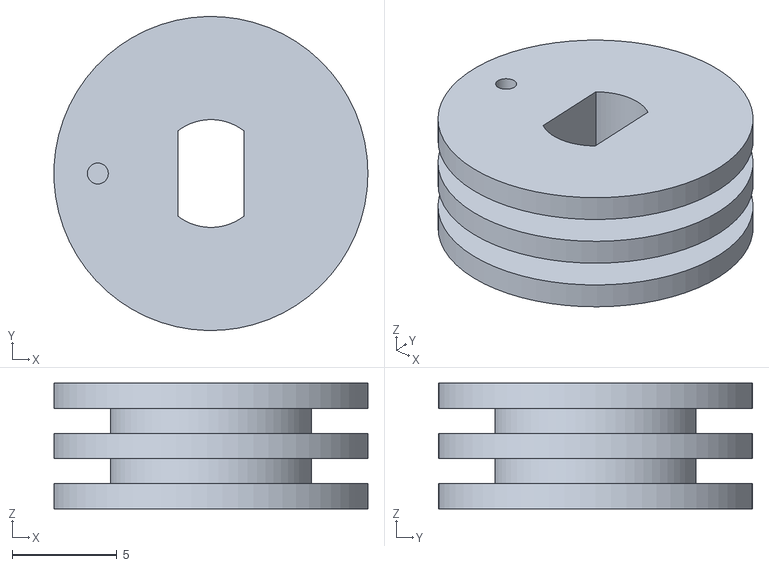
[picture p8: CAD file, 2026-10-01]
hardware/print/v0/spool_r5.stl
15.0 x 15.0 x 6.00

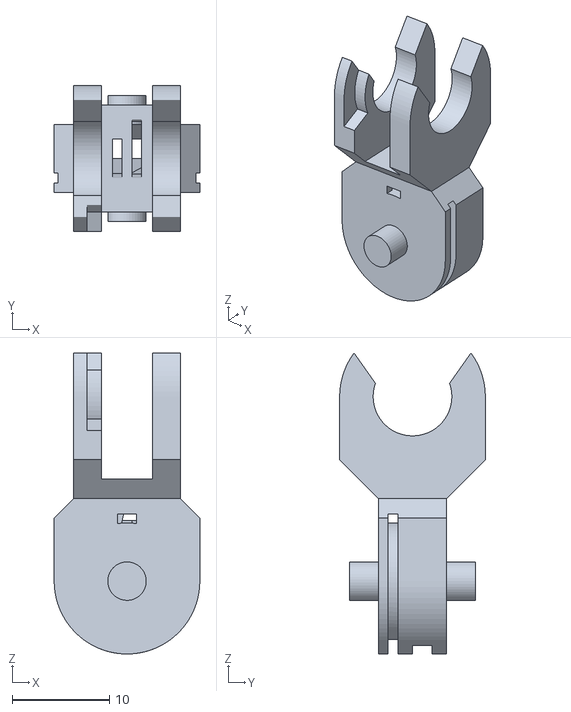
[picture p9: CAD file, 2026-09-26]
hardware/robot_description/fusion_export/meshes/Indexfix_1.stl
15.0 x 15.0 x 31.0

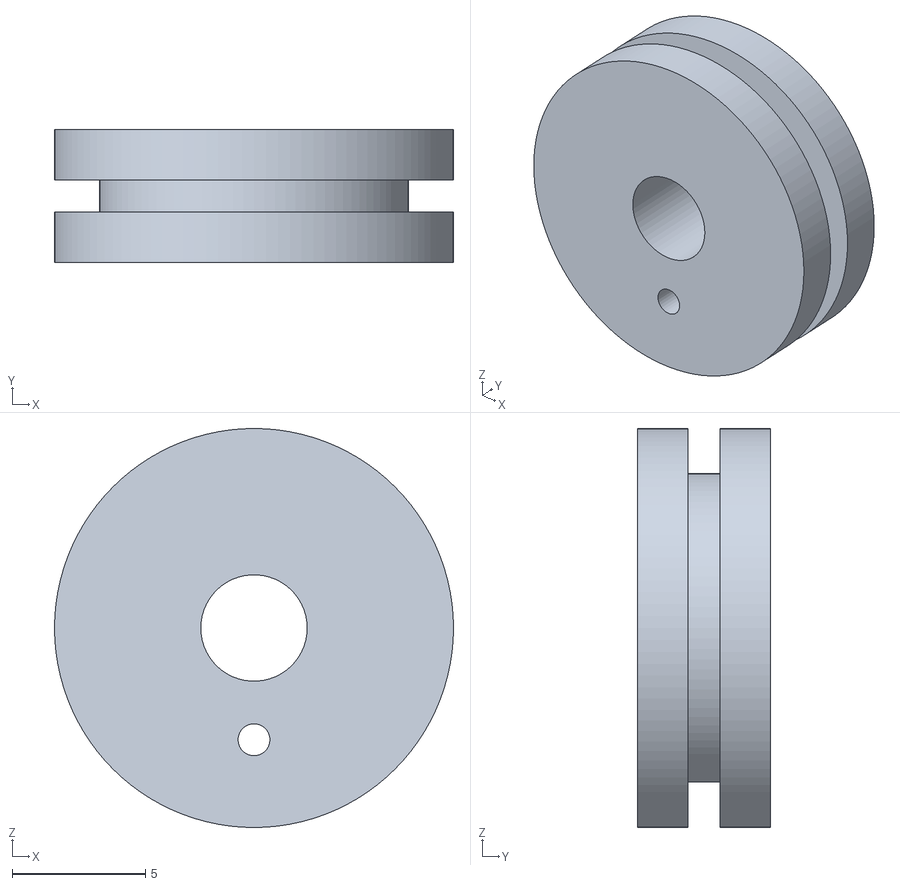
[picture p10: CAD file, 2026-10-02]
hardware/robot_description/v1_export_left/meshes/spool_05_thumb_ip.stl
15.0 x 5.00 x 15.0

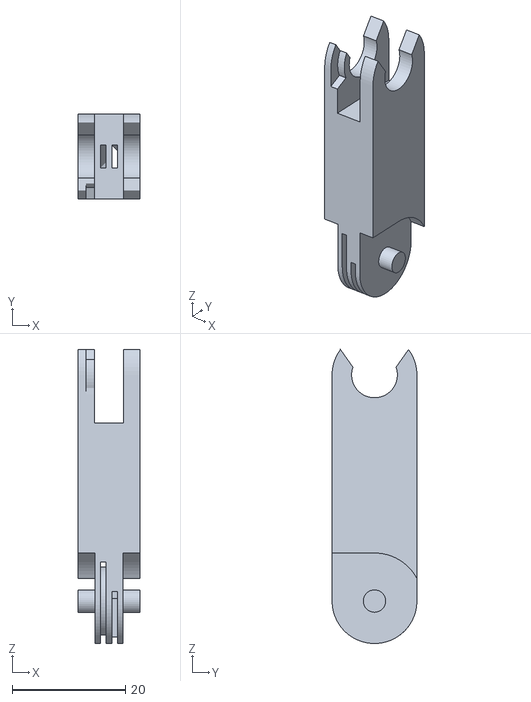
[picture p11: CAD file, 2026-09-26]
hardware/robot_description/fusion_export/meshes/Indexend_1.stl
11.0 x 15.0 x 52.0

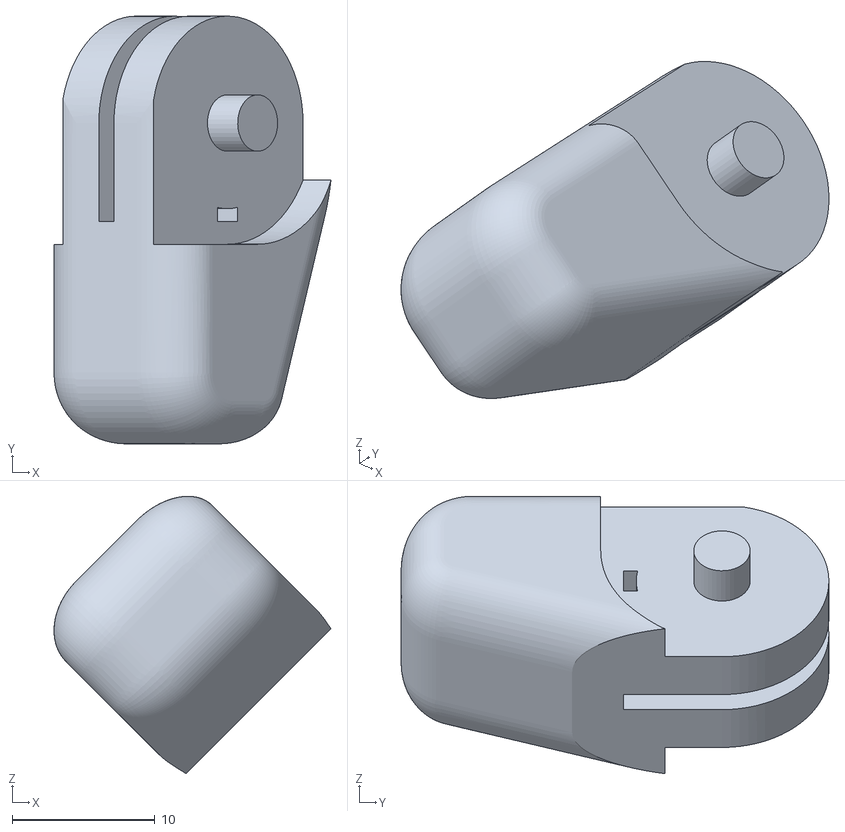
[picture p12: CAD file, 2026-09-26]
hardware/robot_description/fusion_export/meshes/Thumbtip_1.stl
19.4 x 30.0 x 19.5

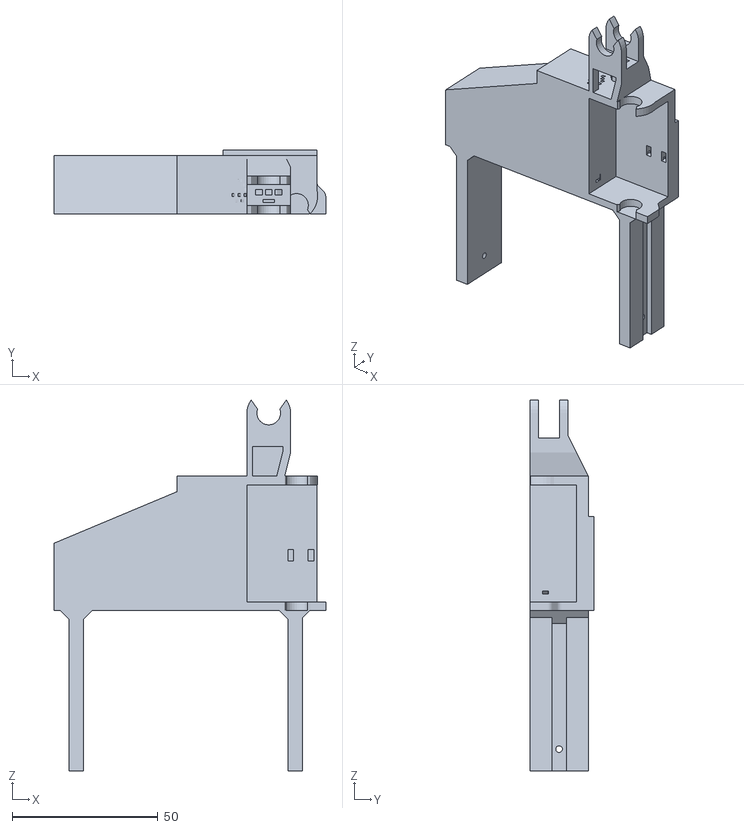
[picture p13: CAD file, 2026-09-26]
hardware/robot_description/fusion_export/meshes/base_link.stl
93.0 x 22.0 x 127.1

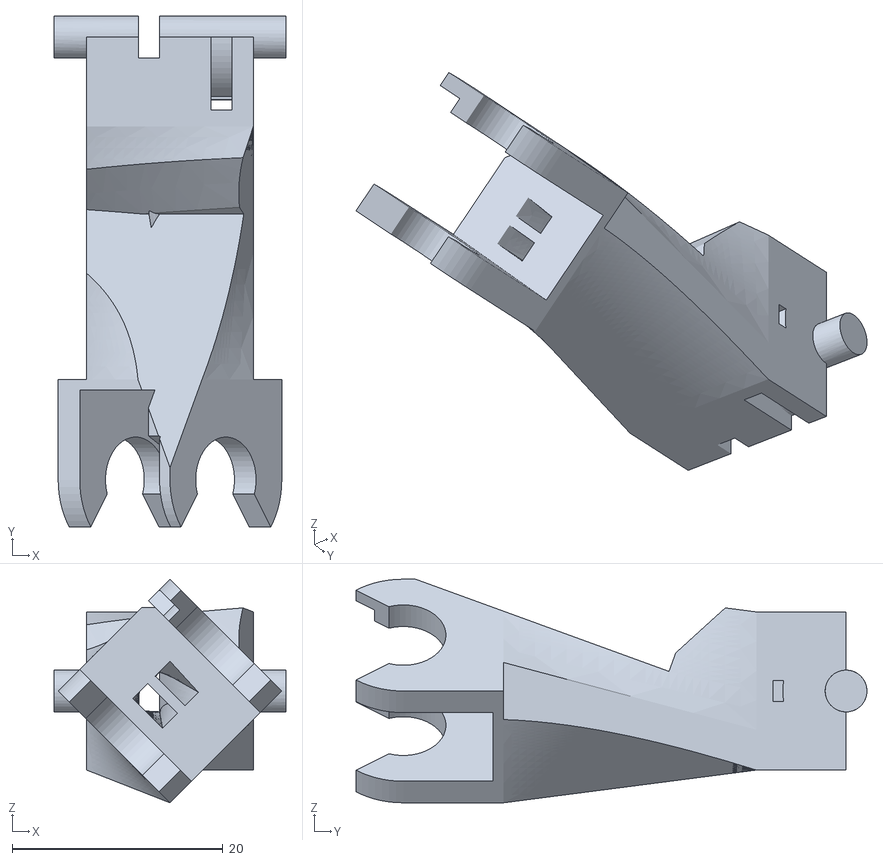
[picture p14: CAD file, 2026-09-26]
hardware/robot_description/fusion_export/meshes/Thumbend_1.stl
22.0 x 48.5 x 21.2

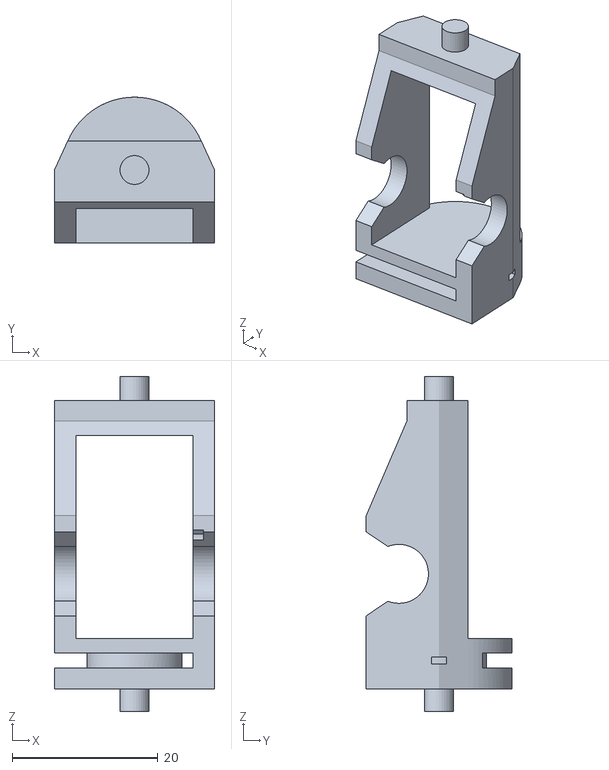
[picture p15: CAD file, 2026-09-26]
hardware/robot_description/fusion_export/meshes/Thumbroll_1.stl
22.0 x 20.0 x 46.0

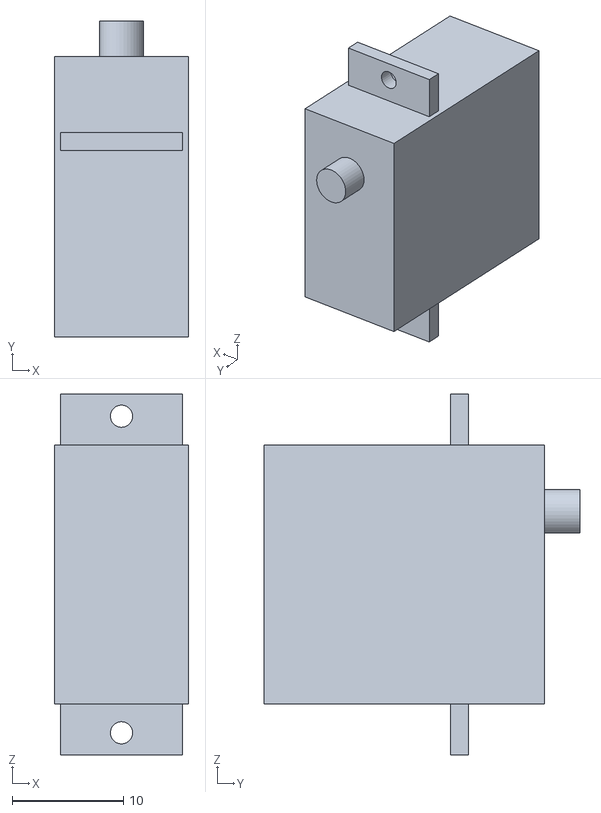
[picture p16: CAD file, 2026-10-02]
hardware/robot_description/v1_export_left/meshes/servo_10_middle_pip.stl
12.1 x 28.5 x 32.5

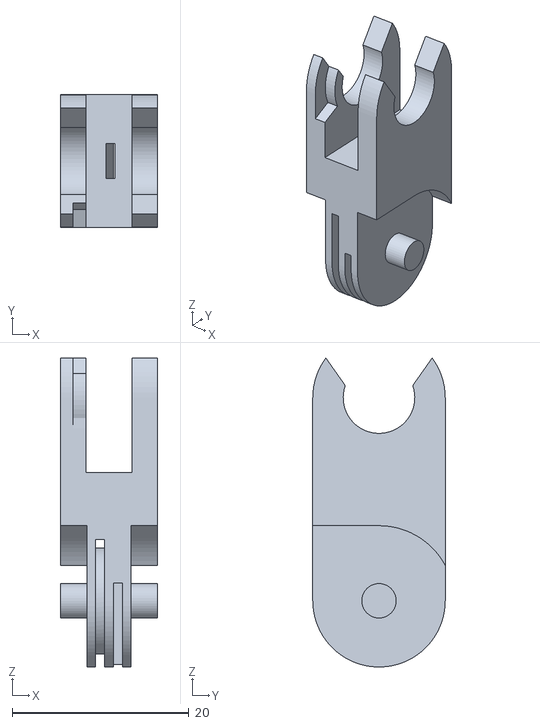
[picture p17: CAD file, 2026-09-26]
hardware/robot_description/fusion_export/meshes/Indexmiddle_1.stl
11.0 x 15.0 x 35.0

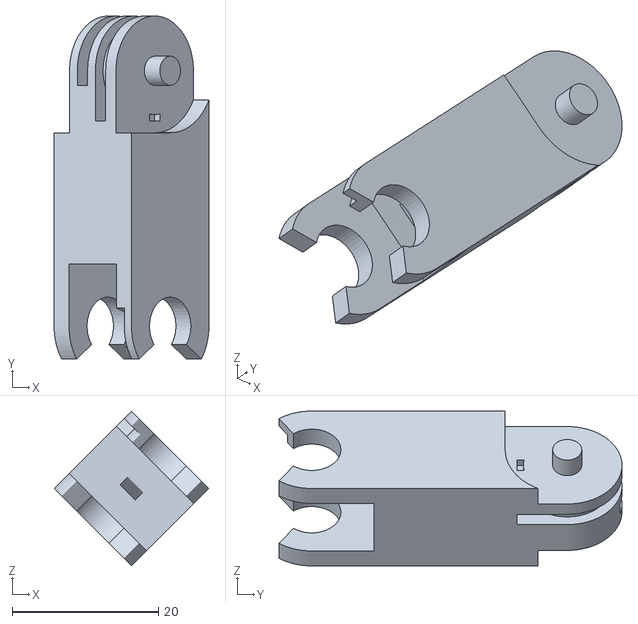
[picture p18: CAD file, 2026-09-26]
hardware/robot_description/fusion_export/meshes/Thumbmiddle_1.stl
21.2 x 47.0 x 21.2

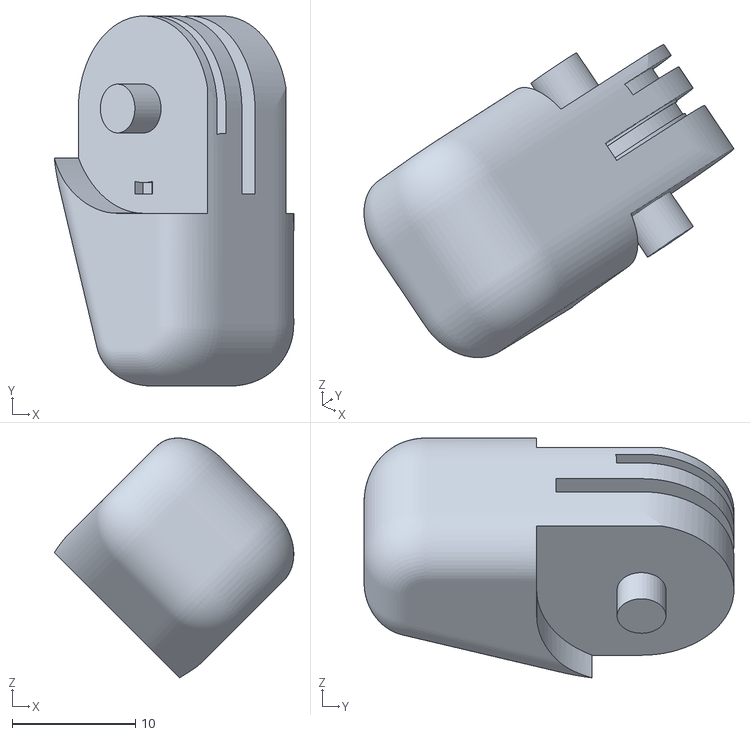
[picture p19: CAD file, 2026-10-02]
hardware/robot_description/v1_export_left/meshes/thumb_distal.stl
19.4 x 30.0 x 19.5

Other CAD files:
hardware/robot_description/v1_export_left/meshes/spool_08_thumb_cmc_rot.stl
hardware/robot_description/v1_export_left/meshes/spool_03_index_mcp_flex.stl
hardware/robot_description/v1_export_left/meshes/spool_13_ring_dip.stl
hardware/robot_description/v1_export_left/meshes/spool_20_little_mcp_abd.stl
hardware/robot_description/v1_export_left/meshes/servo_17_little_dip.stl
hardware/robot_description/fusion_export/meshes/Indextip_1.stl
hardware/robot_description/v1_export/meshes/forearm.stl
hardware/robot_description/v1_export/meshes/index_base.stl
hardware/robot_description/v1_export/meshes/index_distal.stl
hardware/robot_description/v1_export/meshes/index_middle.stl
hardware/robot_description/v1_export/meshes/index_proximal.stl
hardware/robot_description/v1_export/meshes/little_base.stl
hardware/robot_description/v1_export/meshes/little_distal.stl
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

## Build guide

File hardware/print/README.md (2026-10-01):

# Print files

Printable parts (STL/3MF), grouped by finger/assembly.

Current materials:
- Rigid skeleton: **PLA or PETG**
- Fingertip pads (planned): **TPU**

Document print settings (layer height, infill, walls, orientation, supports) next to the files.

## `v0/`: V0 prototype parts

| File | What | Print |
|---|---|---|
| `spool_r5.stl` | Tendon spool for the 28BYJ-48, 5 mm radius: **2× the pull** of the original 10 mm spool, half the speed. Two grooves (flex / ext strand), a tie hole through the outer flange next to each, double-D bore for the 5 mm shaft (slide fit, add a drop of glue if loose). Made by `hardware/cad/spool_v0.py` (`--radius` for other sizes). | PLA/PETG, flat side down, 0.12–0.16 mm layers, 100% infill (it's tiny), no supports |

After fitting a 5 mm spool, the joint moves about **twice as far per motor step**, so re-calibrate that joint's steps per radian (`K i s`, roughly double the old value). Thread each strand from its groove through its tie hole and knot it on the outside; wind flex and ext in opposite directions.

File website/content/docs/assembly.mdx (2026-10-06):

---
title: Assembly
description: Step-by-step assembly of the Tendra Hand thumb and index prototype. The outline is here; detailed steps and photos are added as the build is documented.
updated: 2026-09-27
---

These are the main stages of putting the prototype together, in order. Detailed instructions and photos for each step are still being written as the first prototype is finished.

<Callout type="note" title="Work in progress">
  Each step below says what happens and why. Exact part names, screw sizes and tendon lengths will be added as the build is documented. If you're building along, the [research log](https://github.com/Danielloka/tendra-hand/blob/main/research/log.md) has the latest notes.
</Callout>

<Steps>
  <Step title="Print and clean up the parts">
    Print the palm and finger bones in PLA or PETG (see the [Build guide](/docs/build-guide#printing)). Remove supports, and make sure the joint holes and tendon channels are clear so the tendons can slide freely.
  </Step>

  <Step title="Assemble the finger joints">
    Join the bones with their hinge pins, one joint at a time. Each joint should swing freely through its full range with no rubbing. Friction here is felt by the motor on every move.
  </Step>

  <Step title="Mount the motors">
    Fix the eight 28BYJ-48 motors in their mounts, with a 1 cm radius spool on each output shaft. Label every motor M1 to M8 now; the numbers are used everywhere (see the pin map in [Electronics](/docs/electronics#motor-and-pin-map)).
  </Step>

  <Step title="Thread the tendons">
    For each joint, run a tendon loop from the motor's spool, along the finger, around the joint and back. One side of the loop closes the joint, the other side opens it. Tension them just enough to remove slack, with every joint straight.
  </Step>

  <Step title="Wire the electronics">
    Connect each motor to its ULN2003 board, and each board to the ESP32-S3 pins in the pin map. Connect the separate 5 V / 2 A supply to the driver boards, and join its ground to the ESP32's ground. Leave the motor power **off** for now.
  </Step>

  <Step title="First power-on, one motor at a time">
    Flash the firmware with only USB connected, then follow the first power-on checklist in [Electronics](/docs/electronics#first-power-on). Straighten every joint by hand before switching on the motor power.
  </Step>
</Steps>

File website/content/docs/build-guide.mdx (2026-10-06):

---
title: Build guide
description: An overview of building the Tendra Hand thumb and index prototype, from printed parts and tendons to motors, electronics and the safety rules.
updated: 2026-09-27
---

This guide gives you the big picture of building the current prototype: a **thumb and index finger with 8 joints**. It explains what each part does and the rules that keep the hand (and you) safe. The detailed, photo-by-photo steps are in [Assembly](/docs/assembly).

<Callout type="warning" title="Not ready for a full build yet">
  The print files, exact print settings and a costed parts list aren't published yet. They will be added as the prototype is finished and documented. Until then, treat this page as a preview of how the build works.
</Callout>

## How the hand works

Each finger is a chain of 3D-printed bones connected by hinge joints. A **tendon** (a thin, strong cord) runs along each joint. When a motor pulls the tendon, the joint bends, the same way muscles in your forearm pull tendons to bend your fingers.

Tendra Hand drives every joint **on its own**, with **one motor per joint**. The tendon runs in a loop around the motor's spool: turning the motor one way closes the joint, turning it the other way opens it. This is called an *antagonistic* loop, because the two halves of the tendon work against each other, like the muscles on the two sides of your arm.

The prototype's 8 joints:

| Finger | Joints |
|---|---|
| Index | knuckle sideways (`index_mcp_abd`), knuckle bend (`index_mcp_flex`), middle joint (`index_pip`), tip joint (`index_dip`) |
| Thumb | base rotation (`thumb_cmc_rot`), base bend (`thumb_cmc_flex`), middle joint (`thumb_mcp`), tip joint (`thumb_ip`) |

## Parts

The main parts of the current prototype:

- **Printed skeleton:** the palm and finger bones.
- **Tendons:** one loop per joint.
- **8 × 28BYJ-48 stepper motors (5 V)** with **8 × ULN2003 driver boards**.
- **ESP32-S3-N16R8** microcontroller board, connected to your PC over USB-C.
- **A separate 5 V / 2 A power supply** for the motors.

The full bill of materials (with quantities and links) lives on the [Hardware](/docs/hardware) page.

## Printing

- **Material:** PLA or PETG for the rigid skeleton. PETG is a little tougher and handles warmth better; PLA is easier to print.
- **Fingertip pads:** TPU (a flexible filament) is planned, for grip.
- **Settings:** layer height, infill, walls, orientation and supports will be listed next to each file in `hardware/print/`.

<Callout type="note">
  The simulation assumes solid PLA (1240 kg/m³, about 131 g for the thumb and index). Real printed parts are lighter because of infill. Once the parts are weighed, the model will be updated.
</Callout>

## Tendons

Each joint has one tendon loop wrapped around its motor's spool. The spool has a **radius of 1 cm**, so one full turn of the motor pulls about 62.8 mm of tendon.

How far a joint bends for a given length of tendon depends on how far the tendon sits from the joint's hinge (its *moment arm*). That distance hasn't been measured yet, so the number of motor steps per radian is **calibrated by hand** for each joint (see [Electronics](/docs/electronics#calibrating-a-joint)).

## Motors

The prototype uses **28BYJ-48 stepper motors**. They're cheap, easy to find and geared down about 64:1 inside, so they're slow but hold their position well.

- About **2038 full steps** (or 4076 half-steps) per turn of the output shaft.
- Top speed around **15 rpm**.
- **Open loop:** the motors don't report where they are. The firmware counts the steps it has sent, so it only knows the position if it knew the starting point.

A planned upgrade replaces them with **Feetech SCS0009** smart servos. Those report their own position, share one data cable (so they need far fewer pins) and remove the need for manual homing.

## Electronics

The ESP32-S3 board receives joint angles from your PC over USB and turns them into motor steps. Each motor has its own ULN2003 driver board, which switches the motor's coils. See [Electronics](/docs/electronics) for the full pin map and the flashing steps.

## Safety rules

<Callout type="warning" title="Read this before the first power-on">
  - **Power budget: 5 V / 2 A.** Each energised 28BYJ-48 draws about 200–250 mA, so eight motors are close to the limit. The firmware switches off the coils of motors that have been still for 1 s.
  - **Nothing moves on boot.** At start-up the firmware sets every motor pin LOW and waits for a command.
  - **Manual homing.** The steppers can't tell where they are. Before power-on, **straighten every joint by hand**. That pose is the zero position (or send `Z` after straightening).
  - **Stay near the power switch** during first tests. A tendon that's too tight, or a motor turning the wrong way, can pull hard.
</Callout>

## What's next

<CardGrid>
  <Card title="Assembly" href="/docs/assembly" kicker="Next step">
    Put the printed parts, tendons and motors together.
  </Card>
  <Card title="Electronics" href="/docs/electronics" kicker="Build">
    Wire the drivers to the ESP32-S3, flash the firmware and check each motor.
  </Card>
</CardGrid>

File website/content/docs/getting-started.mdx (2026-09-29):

---
title: Getting started
description: What Tendra Hand is, what's in the repository, and how to run the simulation and tests on your own computer in a few minutes.
updated: 2026-09-27
---

Tendra Hand is an open-source robotic hand that is 3D-printed and driven by tendons, like a human hand. The long-term goal is a robot that can do what people do, like cooking and chores, as well as a person, and the hand is where it starts: a hand with the same joints as yours. Everything is open: the CAD files, firmware, Python code, simulation and research notes.

Right now the project is in **Phase 1**: a thumb and an index finger with **8 joints**, each driven by its own motor. You don't need the hardware to start. The simulation runs on any normal laptop.

<Callout type="note" title="Where things stand">
  The software side (simulation, Python API, firmware) works today. The printable parts, a full build guide and a parts list with prices are still being written up. This page only lists commands that exist in the repository right now.
</Callout>

## What's in the repository

| Folder | What's in it |
|---|---|
| `hardware/` | CAD, print files, electronics notes and the robot model exported from Fusion 360 |
| `firmware/` | Code for the ESP32-S3 microcontroller that moves the motors (PlatformIO) |
| `sim/` | The MuJoCo simulation: model converter, viewer and digital twin |
| `software/` | The `tendra` Python package: one API for the simulated and the real hand |
| `docs/` | Roadmap and guides |
| `research/` | The research log: dated notes on every experiment and decision |
| `website/` | This website |

## What you need

- **Git**, to download the code.
- **[uv](https://docs.astral.sh/uv/)**, a fast Python package manager. It installs the right Python version (3.12) for you, so you don't need to set up Python yourself.
- Any recent Windows, macOS or Linux computer. No graphics card is needed: MuJoCo runs on the CPU.

## Get the code

```sh title="Terminal"
git clone https://github.com/Danielloka/tendra-hand.git
cd tendra-hand
```

## Install the Python environment

From the repository root:

```sh title="Terminal"
uv sync
```

This creates a private Python 3.12 environment in `.venv/` and installs MuJoCo, NumPy, pySerial and the `tendra` package itself. You only need to do it once (and again after pulling changes that add dependencies).

## Open the hand in the simulator

```sh title="Terminal"
uv run python sim/view.py
```

A MuJoCo window opens with the thumb and index finger. In the right-hand panel, open **Control**: there is one slider per motor (M1 to M8). Drag them to bend the joints.

<Callout type="tip">
  Mouse controls: left-drag rotates the view, right-drag moves it, and the scroll wheel zooms. Double-click a part to select it, then Ctrl + right-drag to push it.
</Callout>

## Try the digital twin without hardware

A **digital twin** is a simulated copy of the real hand that stays in sync with it. You move the sliders in the simulator, and the same targets are sent to the real hand. With `--fake`, a software stand-in for the ESP32 takes the place of the real board, so you can try it with no hardware at all:

```sh title="Terminal"
uv run python sim/twin.py --fake
```

The terminal shows how far the (fake) hand is from the simulation as it catches up.

## Use the Python API

The same `Hand` interface drives both the simulation and the real hand, so code written for one runs on the other. Angles are in radians, and positive always means closing the hand.

```python title="example.py"
from tendra import SimHand

hand = SimHand()                     # the MuJoCo simulation
hand.set_joint("index_pip", 0.8)     # bend the index middle joint ~46°
hand.set_targets([0.5] * 8)          # all joints, motor order M1..M8
hand.wait()                          # run the physics until the joints arrive
print(hand.positions())              # measured angles, in radians
```

Swap `SimHand()` for `RealHand()` to talk to the real hand over USB. See `software/README.md` for the full list of methods.

## Run the tests

```sh title="Terminal"
uv run pytest
```

The tests check the simulation model and the Python package. They also make sure the joint names and limits agree across the firmware, the Python code and the MuJoCo model, so a change in one place can't silently break another.

## Where to go next

<CardGrid>
  <Card title="Simulation setup" href="/docs/simulation-setup" kicker="Software">
    How the MuJoCo model is made from the CAD export, and what the converter fixes.
  </Card>
  <Card title="Build guide" href="/docs/build-guide" kicker="Build">
    An overview of building the thumb and index prototype, with the safety rules.
  </Card>
  <Card title="Electronics" href="/docs/electronics" kicker="Build">
    The ESP32-S3, motor drivers, pin map, flashing and the serial protocol.
  </Card>
</CardGrid>

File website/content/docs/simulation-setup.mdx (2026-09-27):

---
title: Simulation setup
description: Run the Tendra Hand in MuJoCo on any laptop, understand how the model is made from the Fusion 360 export, and use the digital twin.
updated: 2026-09-27
---

The simulation is a virtual copy of the hand. You can use it to try out motions, test code before it touches real motors, and, later, train AI controllers. It runs in [MuJoCo](https://mujoco.org/), a free, open-source physics engine made for robotics.

<Callout type="tip" title="No graphics card needed">
  MuJoCo runs on the CPU, so any recent laptop works. The project itself is developed on a laptop with integrated Intel graphics.
</Callout>

## Quick start

From the repository root (you need [uv](https://docs.astral.sh/uv/); see [Getting started](/docs/getting-started)):

```sh title="Terminal"
uv sync                                  # first time only
uv run python sim/view.py                # open the hand in the viewer
uv run python sim/twin.py --fake         # digital twin with a software ESP32
uv run python sim/twin.py --port auto    # digital twin driving the real hand
```

In the viewer, open **Control** in the right-hand panel. Each slider moves one joint, in motor order M1 to M8.

## Files

| File | What it does |
|---|---|
| `sim/convert.py` | Turns the Fusion 360 export into the MuJoCo model, fixing it along the way |
| `sim/models/tendra_hand.xml` | The generated model. **Don't edit it by hand**: re-run `convert.py` instead |
| `sim/view.py` | Interactive viewer with a slider per joint |
| `sim/twin.py` | The digital twin (see below) |
| `sim/tests/` | Sanity checks for the model, run with `uv run pytest` |

## From CAD to simulation

The hand is designed in **Fusion 360**. The **fusion2urdf** plugin exports it as a **URDF**, a common file format that describes a robot's parts, joints and masses. The raw export is kept, unedited, in `hardware/robot_description/fusion_export/`.

MuJoCo has its own format, **MJCF**. The script `sim/convert.py` reads the URDF and writes `sim/models/tendra_hand.xml`. Keeping every fix in the script (and never editing the export) means the design can be re-exported from Fusion at any time and converted again in one command:

```sh title="Terminal"
uv run python sim/convert.py && uv run pytest
```

The tests fail if the committed model is out of date with the converter, so you'll notice if you forget.

### What the converter fixes

The raw export has a few problems. The converter fixes them all:

- **Wrong material.** Fusion's default material is steel, so the export says the parts weigh 821 g in total. The converter recomputes each part's mass from its 3D mesh at PLA density (1240 kg/m³), which gives about **131 g**.
- **Invalid inertias.** The export rounds inertia values so much that two parts end up physically impossible. The converter recomputes them from the meshes.
- **Joint names.** Joints get descriptive names like `index_pip` and `thumb_cmc_rot` instead of `Revolute 3`.
- **Directions.** Every joint is set up so that **positive closes the hand** and 0 is straight. Two thumb joints had their axes the other way round in the export.
- **Actuators.** One simple position controller per motor, in motor order. They stand in for the stepper and tendon until the real motors are measured.
- **Collisions.** A few contacts are turned off that only exist because of how the model is simplified: the palm is fixed in place, and the palm's collision shape is a rough "shrink-wrap" that touches the thumb even when the real parts don't.

<Callout type="note" title="Known limits">
  The masses assume solid plastic, while printed parts are lighter. The actuator strength is a placeholder. And the palm's collision shape is approximate. All three are on the roadmap: weigh the parts, measure the real motors (*system identification*), and split the palm into several convex pieces.
</Callout>

## The digital twin

A **digital twin** is a simulated copy of the hand that runs alongside the real one. In version 1, it works in one direction: you move the sliders in the simulator, and the same joint targets are sent to the real hand.

- `--fake` uses a software stand-in for the ESP32, so you can try everything with no hardware.
- `--port auto` finds the real ESP32 on USB. You can also name the port, like `--port COM5`.
- Targets are sent only when they change, and at most 20 times per second.
- The terminal shows how far the real hand's step counters are from the simulation.

<Callout type="warning">
  Before connecting to the real hand, straighten all its joints by hand and power up (or send `Z`). Nothing is sent until you move a slider, so the hand never moves on start-up.
</Callout>

Version 2 will also work the other way: once the smart servos report their positions, the simulation will show what the real hand is *actually* doing, not only what it was told to do.

## Later: Isaac Sim and Isaac Lab

For large-scale AI training, NVIDIA's [Isaac Lab](https://isaac-sim.github.io/IsaacLab/) can run thousands of simulated hands in parallel. It needs an NVIDIA graphics card, so if the project uses it, training will run on rented cloud GPUs. For now, MuJoCo covers everything the project needs.

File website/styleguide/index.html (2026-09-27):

Skip to content

Tendra Hand

GitHub (https://github.com/Danielloka/tendra-hand)

Open source prototype

# A robotic hand anyone can build.

Print it, string it, and watch it move. Every design file and every line of code is free, for everyone.

Get started See how it works

Product photo goes here

8 moving joints today

131g of printed plastic

100% open source

Colour

## Mostly white space. A touch of blue.

Blue is only for things you can click. Everything else stays calm and neutral, so the hand itself is the star. Values and contrast are read live from the CSS, so switch to dark mode to check both themes.

### Backgrounds & lines

### Text — contrast against the page

### Accent

Typography

## One typeface. Clear at every size.

Inter for everything: big and bold for headlines, relaxed for reading. Sizes grow smoothly from phone to desktop.

Display44 → 104 px · BoldHello, hand.

Heading 136 → 68 px · BoldBuilt to be rebuilt

Heading 228 → 48 px · SemiboldMoves like yours

Heading 322 → 30 px · SemiboldOne motor for every joint

Heading 418 → 20 px · SemiboldPrint it at home

Lead18 → 24 px · Regular

Strong, quiet and surprisingly gentle. Made from parts you can print yourself.

Body16 → 17 px · 65 characters wide

Each finger joint is pulled by a thin cord, like the tendons in your own hand. A small motor winds the cord one way to bend the finger and the other way to straighten it, so every joint moves on its own.

Caption13 px

Weight measured from the 3D model. Printed parts are usually a little lighter.

Space, corners & depth

## Room to breathe.

Generous spacing, softly rounded corners, and shadows so light you almost don't see them.

### Spacing · 4 px steps

### Corner radius

Small · 8

Medium · 14

Large · 22

XL · 32

### Shadows

Small

Medium

Large

Motion

## Smooth, never showy.

Things start quickly and settle softly, just like the hand's own motors. If your device asks for less motion, the site keeps still.

Ease out — the default. cubic-bezier(0.22, 1, 0.36, 1)

Ease in-out — moving between two states. cubic-bezier(0.65, 0, 0.35, 1)

Linear — for comparison only.

Play Durations: fast 150 ms · base 300 ms · slow 700 ms

Buttons

## One clear next step.

Each screen gets one blue button for the main action. Everything else is quieter.

Download files Read the guide Join the project Learn more Disabled

Small Default Large

Primary · Secondary · Outline · Text link. Press Tab to see the focus ring.

Cards

## Simple parts. Big ideas.

Soft, rounded cards. Hover one and it lifts a little, with a link to learn more.

Hardware

### Print it yourself

Every part is made on an ordinary 3D printer. Download the files and start today.

Get the files

Motion

### Moves like a real hand

Thin cords act like tendons. Small motors pull them to bend and straighten each finger, smoothly.

See how it works

Software

### Try it on your computer

A virtual copy of the hand runs on any laptop. Move it on screen and the real one follows.

Open the simulator

Tech specs

## All the details.

Clear rows, plain words, numbers that line up.

Prototype 1 · in progress

Fingers

Thumb and index (full hand coming later)

Moving joints

8, four per finger

Weight

131 g of printed parts

Motors

8 small stepper motors, one per joint

Brain

ESP32-S3 microcontroller

Connection

USB-C to your computer

Power

5 V, 2 A adapter

Licence

Open source, free to use and change

Tags

## Status at a glance.

Prototype In progress Done Open source Planned Apache-2.0

Blue = new or open. Amber = in progress. Green = done. Grey = planned or just facts.

Code

## Five lines to wave hello.

Code blocks are soft and easy to copy. Inline code looks like hand.open().

pinch.pyCopy

from tendra import SimHand

# The same code drives the simulation and the real hand
with SimHand() as hand:
    hand.set_joint("index_pip", 0.9)
    hand.set_joint("thumb_cmc_rot", -0.6)
    hand.open()

TerminalCopy

# try the hand without any hardware
$ uv run python sim/twin.py --fake

Details

## Small touches.

How to use the built-in effects on any page.

Heading reveal

data-reveal="lines"

Fade in on scroll

data-reveal, optional --reveal-delay

Counting numbers

data-count-to="131"

Frosted nav

Automatic when you scroll

Less motion

Everything shows instantly

Tendra Hand · Style guide v0.2 Code Apache-2.0 · Hardware CERN-OHL-S-2.0 · Docs CC BY 4.0

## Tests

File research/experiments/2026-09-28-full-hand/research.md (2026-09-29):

# Full hand (v1) research: SCS0009 servos, tendons, proportions, power

Date: 2026-09-28. Scope: research input for the v1 CAD, a 21-DOF tendon-driven hand with one Feetech SCS0009 per joint (antagonistic loop on one spool), 42 strands of 0.4 mm line, and servos in the forearm.

Units are mm, g, N·m and A. Where a number comes from my reading of a drawing, from memory, or from a single non-official source, it is marked **(unverified)**.

---

## 1. Feetech SCS0009: exact specs

Main source: the official Feetech product specification, model SCS0009, edition A/0, dated 2020-11-23 ([Seeed mirror](https://files.seeedstudio.com/products/Feetech/SCS0009-Specifications.pdf), [Switch Science mirror](https://pages.switch-science.com/comparison/files/feetech/serial-scs/SCS0009_datasheet.pdf)). I rendered and read the dimension drawing on page 6 myself.

### 1.1 Mechanical (datasheet drawing, page 6)

| Item | Value | Note |
|---|---|---|
| Body L × W × H (no tabs, no spline) | **23.2 × 12.1 × 25.25** | The table says 23.2. The drawing dimensions the length as 23.3. Design for 23.3. |
| Length over the mounting tabs | **32.5** | 2 × 16.25 from the body centre |
| Tab width | **11.0** (unverified) | The drawing's "11" dimension. It is 1.1 narrower than the body. |
| Tab thickness | **1.6** | The tab underside is 16.8 above the case bottom and the top is 18.4 |
| Mounting holes | **2 × Ø2.0**, **28.5 centre to centre** | 2 × 14.25, symmetric about the body centre. Hole centre is 2.0 from the tab tip. |
| Output shaft, along the length | **5.7 from the body centre**, so **≈5.9 from the near end face** (23.3/2 − 5.7 = 5.95) | Shaft is 8.55 from the nearer hole |
| Output shaft, across the width | Centred (6.05 from each side) | |
| Case top (main body shoulder) | 21.45 above the case bottom | A small cap/boss rises to 25.25 |
| Top of cap around the shaft | **25.25** above the bottom = **6.85 above the tab top** | |
| Top of spline | **28.45** above the bottom = **10.05 above the tab top**, 3.2 above the cap | The drawing also shows 2.9, probably the toothed length of the spline (unverified) |
| Spline / horn | **20 teeth, OD 3.95**, horn screw **M2 × 4** into the shaft | Not the common 25T. The datasheet lists **no accessories**, so a horn may not come in the box. |
| Weight | **13.2 ± 1 g** | 21 servos ≈ 277 g |
| Gears / case | Copper + steel gears, PC case | |
| Gear ratio | 1/416 in the datasheet | An older Feetech FAQ says "SCS009: 256:1" (probably an older model). **Conflict: trust the datasheet.** |
| Backlash | ≤ 0.5° | |
| Cable / connector | 15 cm, Molex 5264-3P, **one lead only** (pin 1 GND, 2 Vcc, 3 signal) | There is no second connector for daisy-chaining. You need a hub or bus board. |
| Position sensor | Carbon-film potentiometer, 330° electrical, 100 000 cycles minimum | |

### 1.2 Electrical

| | 4.8 V | 6 V |
|---|---|---|
| Stall torque | 1.89 kg·cm = **0.185 N·m** | 2.3 kg·cm = **0.226 N·m** |
| Rated (continuous) torque | 0.65 kg·cm = 0.064 N·m | 0.75 kg·cm = 0.074 N·m |
| No-load speed | 0.125 s/60° (80 rpm) | 0.10 s/60° (100 rpm) |
| Idle current (stopped) | 5 mA | 6 mA |
| No-load running current | 120 mA | 150 mA |
| Rated current | 300 mA | 400 mA |
| Stall current | **0.8 A** | **1.0 A** |

- Input range **4.0–7.4 V**. Typical is 6 V. Feetech recommends 4.8–6 V for the SCS009 class ([Feetech URT-1 tutorial](https://www.feetechrc.com/Data/feetechrc/upload/file/20201127/start%20%20tutorial201015.pdf)).
- Protections: overload (load > 80 % for 2 s, then torque drops until a new command arrives), voltage (< 4 V or > 9 V), temperature (> 70 °C). All are adjustable.
- **Design consequence:** a pretensioned antagonistic loop loads the servo all the time. If pretension plus holding load stays above about 80 % for 2 s, the servo **backs off by itself**. Keep pretension low (a few N), or tune registers 37–39.

### 1.3 Control

- Position range **0–1023 = 300°**, so **0.293° per step**. Neutral is 511. Rotation is clockwise for 0 → 1023. Absolute position only: **no multi-turn**. Position is lost outside the pot's range.
- Modes: mode 0 is position servo (default, 0–300°). Mode 2 is "open-loop speed motor mode" (wheel/PWM mode), selected by setting the min and max angle limits to 0. Then the goal-time register holds the PWM value, and bit 10 sets the direction.
- Bus: TTL, half-duplex, asynchronous, 8N1. **Default 1 Mbps** (38 400 bps to 1 Mbps). IDs 0–253 (254 = broadcast). **Default ID = 1**, so give each servo its ID one at a time before chaining them.
- Signal levels: high 2–5 V, low 0–0.45 V, so **3.3 V logic is inside spec**. Max position update rate 1 ms.

### 1.4 Protocol (SCS)

Packet: `0xFF 0xFF ID LEN INSTR PARAM… CHECKSUM`, where LEN = number of params + 2 and CHECKSUM = ~(ID + LEN + INSTR + params) & 0xFF. This comes from `SCS::writeBuf` in the official library.

Instructions: PING 0x01, READ 0x02, WRITE 0x03, REG_WRITE 0x04, ACTION 0x05, RESET 0x0A, SYNC_WRITE 0x83. SYNC_READ 0x82 exists in the library, but **the SCS0009 does not support sync read** ([pollen-robotics/rustypot scs0009.rs](https://github.com/pollen-robotics/rustypot/blob/develop/src/servo/feetech/scs0009.rs): `supports_sync_read: false`). Read feedback one servo at a time.

**Byte order: big-endian (high byte first).** The Feetech FAQ says "SCS series high byte first, SMS low byte first". In the library, `SCSCL()` sets `End = 1`, and `Host2SCS` then writes the **high byte to the "_L" address**. This is the opposite of STS/SMS.

Baud codes (register 6), per Feetech: 0 = 1 M, 1 = 500 k, 2 = 250 k, 3 = 128 k, 4 = 115 200, 5 = 76 800, 6 = 57 600, 7 = 38 400. rustypot has a different table from code 5 up; trust Feetech's.

Register map (official library [ftservo/FTServo_Arduino `src/SCSCL.h`](https://github.com/ftservo/FTServo_Arduino/blob/main/src/SCSCL.h), MIT licence, plus rustypot for the extra addresses):

| Addr | Name | Size | Area | Notes |
|---|---|---|---|---|
| 3 | model / version | 2 | EEPROM R | rustypot: SCS0009 model number is 1284 |
| 5 | ID | 1 | EEPROM RW | |
| 6 | baud rate | 1 | EEPROM RW | codes above |
| 7 | return delay | 1 | EEPROM RW | rustypot |
| 8 | response status level | 1 | EEPROM RW | rustypot |
| 9 | min angle limit | 2 | EEPROM RW | 0 and 0 at 9 and 11 selects wheel mode |
| 11 | max angle limit | 2 | EEPROM RW | |
| 13 | max temperature | 1 | EEPROM RW | |
| 14 / 15 | max / min voltage | 1 / 1 | EEPROM RW | units 0.1 V |
| 16 | max torque limit | 2 | EEPROM RW | 0–1000 = 0–100 % of stall (Feetech FAQ). Useful for gentle grasps. |
| 19 | unloading condition | 1 | EEPROM RW | bit flags: 32 overload, 4 temperature, 1 voltage |
| 21 / 22 / 23 | P / D / I | 1 each | EEPROM RW | |
| 24 | min startup force | 2 | EEPROM RW | |
| 26 / 27 | CW / CCW dead band | 1 each | EEPROM RW | |
| 37 / 38 / 39 | protective torque / protection time (×40 ms) / overload threshold (%) | 1 each | RW | see the overload note above |
| **40** | **torque enable** | 1 | SRAM RW | 0 = free, 1 = holding |
| 41 | acceleration | 1 | SRAM RW | rustypot. The library forces ACC = 0 on SCS. |
| **42** | **goal position** | 2 | SRAM RW | 0–1023 |
| **44** | **goal time** | 2 | SRAM RW | ms. In wheel mode this is the PWM (bit 10 = direction). |
| **46** | **goal speed** | 2 | SRAM RW | 0 = max. The unit is unclear: the example comments say 0.059 rpm per unit (written for SCS15), rustypot says steps/s. **Calibrate.** |
| 48 | lock | 1 | SRAM RW | write 0 to unlock the EEPROM before changing the ID, then 1 |
| **56** | **present position** | 2 | SRAM R | |
| 58 | present speed | 2 | SRAM R | sign on bit 15 |
| **60** | **present load** | 2 | SRAM R | 0–1000 = PWM duty to the motor (‰), sign on bit 10. This is **not** a current reading. |
| **62** | **present voltage** | 1 | SRAM R | 0.1 V |
| **63** | **present temperature** | 1 | SRAM R | °C |
| 65 | status | 1 | SRAM R | |
| 66 | moving | 1 | SRAM R | |
| 69 | present current | 2 | SRAM R | listed in the library, sign on bit 15. **May be unimplemented on the SCS0009** (a Feetech FAQ says the SCS series has no current detection). |

**Library.** Use the official **FTServo_Arduino** (Feetech, MIT). The older "SCServo" copies (for example `workloads/scservo`) have identical SCSCL code. Class **`SCSCL`** (`#include <SCServo.h>`). Set `sc.pSerial = &Serial1` after `Serial1.begin(1000000, SERIAL_8N1, RX, TX)`. Functions:
- `WritePos(id, pos, time, speed)`, `RegWritePos` + `RegWriteAction`, `SyncWritePos(ids[], n, pos[], time[], speed[])`
- `EnableTorque(id, 0/1)`, `unLockEprom(id)` / `LockEprom(id)`, `writeByte(id, SCSCL_ID, newId)`
- `FeedBack(id)` (reads 56–70 in one go), `ReadPos`, `ReadSpeed`, `ReadLoad`, `ReadVoltage`, `ReadTemper`, `ReadMove`, `ReadCurrent`
- `PWMMode(id)`, `WritePWM(id, pwm)`, `Ping(id)`

**Bus timing (estimate).** At 1 Mbps a byte takes 10 µs. A SYNC_WRITE of goal position + time + speed to all 21 servos is 8 + 21 × 7 ≈ 155 bytes ≈ **1.6 ms**. With no sync read, one position read is about 8 bytes out + 8 bytes back plus the turnaround, about 0.2–0.3 ms, so all 21 take **≈5–6 ms**. That gives about **100–150 Hz** for full-state feedback.

### 1.5 FE-URT-1 to ESP32-S3

From the Feetech URT-1 tutorial (link above, FAQ items 6–7 and its wiring figure):
- Connect the URT-1 UART header **TX–TX, RX–RX, V–5 V, GND–GND**. The labels are printed from the MCU's side, so **do not cross them**. If nothing responds, try swapping them. Owners on the Arduino forum confirm it works with an ESP32 at 1 Mbps ([thread](https://forum.arduino.cc/t/how-to-connect-esp-32-to-feetech-urt-1-to-control-scs-serial-bus-servos/1051765)).
- Set the board's **level switch to 3.3 V** for the ESP32. The figure note says "Arduino level switch 5V, STM32 level switch 3.3V".
- **"USB port and UART port cannot be used at the same time."** Leave the URT-1's mini-USB unplugged when the ESP32 drives it.
- The URT-1 does **half-duplex switching in hardware** (no direction/enable pin), so a plain `HardwareSerial` works.
- Servo power goes into the blue screw terminal (4.8–8.4 V for SCS). Its current rating is not published (unverified). For 21 servos, feed power through your own distribution board and let the URT-1 carry only signal and GND.
- ESP32-S3: use UART1 on any free GPIO, for example TX = GPIO 17 and RX = GPIO 18. None of the octal-PSRAM or strapping-pin problems from v0 apply, and PSRAM can be turned back on. The ESP32-S3 is **not 5 V tolerant**, so never skip the URT-1 and wire a servo line straight to a GPIO.

---

## 2. Tendon force budget and spool radius

The tendon force at the spool is F = τ / r_spool. With a joint drum of radius r_joint and both strands of the loop on it, the joint torque is τ_joint = τ_servo × r_joint / r_spool. A joint angle Δq needs a servo angle of Δq × r_joint / r_spool.

SCS0009 at 6 V, joint drum r_joint = 6 mm:

| r_spool | Tendon force at stall / rated | Joint torque at stall | Servo degrees per joint degree | Joint resolution |
|---|---|---|---|---|
| 5 mm | 45.1 / 14.7 N | 0.271 N·m | 1.2 | 0.24° |
| **6 mm** | **37.6 / 12.3 N** | **0.226 N·m** | **1.0** | **0.29°** |
| 8 mm | 28.2 / 9.2 N | 0.169 N·m | 0.75 | 0.39° |
| 10 mm | 22.6 / 7.4 N | 0.135 N·m | 0.6 | 0.49° |

Tendon excursion with a 6 mm moment arm:

| Joint | Range | Excursion | Servo angle at r = 6 |
|---|---|---|---|
| MCP flex | −10…+90° (100°) | 10.5 mm | 100° |
| PIP | −5…+100° (105°) | 11.0 mm | 105° |
| DIP | −5…+80° (85°) | 8.9 mm | 85° |
| MCP abd | ±20° (40°) | 4.2 mm | 40° |
| Thumb CMC rot (v0 range) | −100…+40° (140°) | 14.7 mm | 140° |

**Travel is not the constraint.** Even the thumb rotation uses under half of the servo's 300° at r = 6 mm. **Force is the constraint.** At 1:1 the index MCP gives about 0.23 N·m at stall and about 0.07 N·m continuous. Over an 80 mm finger that is about **2.8 N at the fingertip at stall and about 0.9 N continuous**, before friction losses (see section 3).

**Recommendation: r_spool = 6 mm**, measured at the tendon centreline, so the groove bottom sits at 5.8 mm.
- It is the smallest radius that still leaves a solid hub around the 3.95 mm spline and the M2 screw.
- It gives 1:1 with the current 6 mm drums, which makes calibration trivial (steps/rad = 1024/300° × r_j/r_s).
- It is still 15× the line diameter, so there is no bending damage to the line.
- **Do not go to 8–10 mm.** You don't need the travel, and you lose 25–40 % of the force.
- If you need more force, **raise r_joint instead** (for example an 8 mm MCP drum gives 0.30 N·m at the joint and 133° of servo travel). You could also drop to r_spool = 5 mm.
- Keep r_joint the same for the flexor and extensor strands of a loop, so both strands change length equally. That is the condition for a single-spool antagonistic loop to stay tight ([Bowden antagonistic hand, arXiv 2512.24657](https://arxiv.org/html/2512.24657v1): residual length mismatch ≈ 0.03 mm).
- Each strand wraps less than half a turn (14.7 mm on a 37.7 mm circumference). Give each strand its own groove on a two-groove spool, about 1 mm groove width and flanges, total width about 5–6 mm, with an anchor hole per strand.
- Build in **pretension adjustment**. Options: a two-part spool clamped by a screw (Shadow Hand), a ratchet spool (ORCA), or a tension screw per strand.
- Line strength: 0.4 mm nylon mono breaks at roughly 80–100 N and braided PE is stronger (typical catalogue values, unverified). That is above the 37.6 N stall force, so a safety factor of about 2 or more.

---

## 3. Reference designs and routing

| Hand | Actuation and routing | Take-away for us |
|---|---|---|
| **ORCA** (ETH SRL, 2025) [arXiv 2504.04259](https://arxiv.org/abs/2504.04259) | 17 DOF. 16× Dynamixel XC330-T288 + 1× XC430 in a tower below the hand. **Two tendons per joint (flexor + extensor)**, 0.4 mm braided nylon. DIP is fixed/coupled. Tendons are deflected around **smooth metal pins and rods**, with **Teflon tubes for non-linear routing** (for example thumb base to wrist). Tendons are routed **through the joint centre of rotation**. They avoid tendon contact with PLA ("every tendon only touches metal and smooth PTFE"). Ratchet spool for re-tensioning. Wrist uses a GT2 belt. Survived more than 10 000 cycles. | This is closest to ours. Copy it: no line-on-PLA sliding, PTFE for curved runs, pins at sharp deflections, and a quick retension. |
| **Shadow Dexterous Hand** [docs](https://shadow-robot-company-dexterous-hand.readthedocs-hosted.com/en/stable/user_guide/md_motor_unit.html) | 20 motors in the forearm, **each driving a pair of agonist/antagonist Spectra tendons on one spool** (exactly our scheme). Split spool for preload, tensioner units, and a 90° turn around a metal bar at the spool exit (which also carries a load cell). Small motors: 65 N continuous, 110 N maximum tendon force. | This validates one spool per joint. The bar at the spool exit is a good pattern: a fixed deflection point, so the angle into the tube never changes. |
| **Antagonistic Bowden hand** [arXiv 2512.24657](https://arxiv.org/html/2512.24657v1) | One Dynamixel per joint, both strands on the same shaft. PTFE sheath **1 mm ID / 2 mm OD** plus a spring jacket, and 0.75 mm coated steel line. Bobbins keyed with an octagon so preload can be set. Keeps bend radii above the minimum. | Confirms PTFE 1/2 mm for sub-1 mm line. |
| **MM-Hand** [arXiv 2604.17245](https://arxiv.org/html/2604.17245) | 21 DOF with a remote Feetech motor hub. Tested sheaths: a plain PTFE tube had "relatively high friction" (extrusion quality). The Bambu PTFE feeder tube and a metal spring tube were better. Software pretension. | Buy good-quality (smooth-bore) PTFE. |
| **DLR Hand Arm System / Awiwi** | About 38 motors in the forearm, two per joint (antagonistic, variable stiffness), Dyneema tendons (from memory, unverified). | Two motors per joint is the high-end option. We use one plus a loop. |
| **InMoov** | Hobby servos in the forearm, one per finger, pull-pull loop of braided line on the horn, printed channels (from memory, unverified). | Bare printed channels work for hobby loads but wear and have high friction. |
| **DexHand** (The Robot Studio) [repo](https://github.com/TheRobotStudio/V1.0-Dexhand) | 16 slim micro servos in the forearm, Sufix 832 braid (80 lb) for the fingers, Feetech SCS2332/SCS15 on the wrist. | Braided PE is the popular line. |
| **ILDA** (Kim et al., 2021) | Linkages driven by motors in the palm, **not tendons** (unverified). | Not comparable. |
| **LEAP Hand** (CMU) | Dynamixels directly in the joints, **not tendons**. | Not comparable. |

**Friction (capstan).** F_out = F_in · e^(−μθ), where θ is the **sum of all bend angles** along the strand (in rad).
- μ for line in a PTFE sheath: **0.04–0.2** (MM-Hand and Bowden literature).
- μ on bare printed PLA: plan **0.3**. Pin-on-disc PLA gives 0.38–0.57 ([Rapid Prototyping J. 2022](https://www.emerald.com/insight/content/doi/10.1108/rpj-03-2022-0081/full/html)), and layer lines abrade the line.
- Transmitted fraction:

| μ \ total wrap | 45° | 90° | 180° | 360° |
|---|---|---|---|---|
| 0.1 (PTFE) | 0.92 | 0.85 | 0.73 | 0.53 |
| 0.2 | 0.85 | 0.73 | 0.53 | 0.28 |
| 0.3 (PLA) | 0.79 | 0.62 | 0.39 | 0.15 |

- Friction scales with tension, so **pretension costs force twice**: it loads both strands and the servo all the time.

**Recommendations**
- **Channel for PTFE tube 1 mm ID × 2 mm OD: 2.2 mm hole** (a snug slip fit in PLA; FDM holes print about 0.1–0.2 mm undersize, so test-print 2.1 / 2.2 / 2.3). Use tubes from the palm base through the wrist to the servo, where the path curves. Anchor each tube end so it cannot slide; a stepped hole down to 1.2 mm makes a shoulder.
- **Bare channel (no tube), 0.4 mm line: 1.2 mm** modelled, which prints to about 1.0 mm. Only use this for short, **straight** runs inside the fingers, or line it with a smooth pin or tube wherever the strand turns.
- **Channel pitch:** at least 3.0 mm centre to centre for 2 mm tubes, which leaves a 1 mm wall. 42 tubes in a 7 × 6 grid take about **21 × 18 mm**, which fits through a wrist about 30 × 45 mm.
- **Minimum bend radius:** tube runs ≥ 15 mm (PTFE 1/2 mm kinks below about 10 mm, unverified). Bare-line deflection over metal pins or a spool ≥ 3 mm (≥ 7× the line diameter); 5 mm is better. Printed curved channels without a tube: avoid, or keep ≥ 10 mm radius and ≤ 30° total.
- **Maximum total wrap per strand:** aim for **≤ 90°** from spool to joint (about 85 % efficiency in PTFE), and never more than 180°. This does not count the wrap on the joint drum itself, which moves with the joint and does not slide.
- Put **fixed deflection points** (a metal pin or bar) where a strand leaves the spool, so the tube entry angle doesn't change as the spool turns. Shadow uses a 90° turn over a bar here.
- **Wrist:** v1 has no wrist DOF, so run the tubes straight through the wrist. If a wrist DOF comes later, route the whole bundle **through the wrist axis**, as with the finger joints, so wrist motion doesn't change tendon lengths.
- Pass-through strands must cross each joint **on its axis** (current rule), or run inside a sheath fixed on both sides of the joint (Bowden-style), which also makes them independent of that joint.

---

## 4. Human hand proportions and ranges

**Phalanx lengths** (bone lengths from X-rays, 66 adults, right hand, mean in mm) ([Buryanov & Kotiuk 2010, Int. J. Morphol. 28(3)](https://scielo.conicyt.cl/pdf/ijmorphol/v18n3/art15.pdf)):

| Finger | Proximal | Middle | Distal | Metacarpal | Tip soft tissue |
|---|---|---|---|---|---|
| Thumb | 31.57 | — | 21.67 | 46.22 | 5.67 |
| Index | 39.78 | 22.38 | 15.82 | 68.12 | 3.84 |
| Middle | 44.63 | 26.33 | 17.40 | 64.60 | 3.95 |
| Ring | 41.37 | 25.65 | 17.30 | 58.00 | 3.95 |
| Little | 32.74 | 18.11 | 15.96 | 53.69 | 3.73 |

**Ratios relative to the same phalanx of the index**, and scaled to our index proximal = 40 mm (v0 has 40 / 23):

| Finger | Proximal ratio | Middle ratio | Distal ratio | Whole finger ratio | Scaled P / M / D (mm) |
|---|---|---|---|---|---|
| Index | 1.00 | 1.00 | 1.00 | 1.00 | 40.0 / 22.5 / 15.9 |
| Middle | 1.12 | 1.18 | 1.10 | 1.13 | 44.9 / 26.5 / 17.5 |
| Ring | 1.04 | 1.15 | 1.09 | 1.08 | 41.6 / 25.8 / 17.4 |
| Little | 0.82 | 0.81 | 1.01 | 0.86 | 32.9 / 18.2 / 16.0 |
| Thumb | 0.79 (P) | — | 1.37 (D vs index D) | — | 31.7 / — / 21.8, metacarpal 46.5 |

These are joint-to-joint bone lengths. Add about 4 mm of pad at the fingertip (6 mm on the thumb).

**Knuckle layout**
- **MCP pitch ≈ 22 mm.** Shadow Hand, a human-sized design, uses 22.0 mm: knuckles at x = +33, +11, −11, −33 mm ([MuJoCo Menagerie shadow_hand](https://github.com/google-deepmind/mujoco_menagerie/tree/main/shadow_hand)). Human palm breadth over metacarpals II–V is about 80–90 mm on skin (unverified), which also gives about 20–22 mm between joint centres.
- **Knuckle arc (distal–proximal):** middle is the most distal. In Shadow, the index and ring knuckles sit 4 mm behind the middle and the little knuckle about 12.5 mm behind (95 / 99 / 95 / 86.5 mm from the palm origin). Use about **0 / −4 / −4 / −12 mm** for middle / index / ring / little.
- **Transverse arch:** real knuckles lie on a dorsal arch, with the ring and especially the little knuckle dropping toward the palm by a few mm. Shadow adds a little-finger metacarpal joint (0–45°) for cupping. For v1, lower the little and ring knuckles by about 3–6 mm (unverified estimate) or leave them flat for simplicity.
- **Finger splay at rest:** a small fan of about 0 / +3 / −3 / −8° (middle / index / ring / little, positive toward the thumb) looks natural. Each finger then gets its own ±20° abduction (estimate).

**Thumb, 5 DOF (typical robot layout, like Shadow TH1–TH5):**
- CMC has 2 DOF: rotation/opposition, and flexion/abduction (two roughly perpendicular, non-intersecting axes on the metacarpal base).
- MCP has 2 DOF: flexion, plus a small abduction.
- IP has 1 DOF: flexion.
- The thumb base sits low on the palm, about 60–70 mm proximal of the index knuckle and rotated about 45° (Shadow thumb base quaternion ≈ 45° about y).

**Joint ranges for all 21 joints** (positive = closing).
- Human sources: AAOS norms (finger MCP 90, PIP 100, DIP 90, thumb MCP 50, IP 80, CMC abduction 70, CMC flexion 15 / extension 20) via [goniometer.io](https://goniometer.io/range-of-motion).
- Robot references: ORCA Table I, and the Shadow model.

| Joint | Human (approx.) | ORCA / Shadow | **Suggested design range** |
|---|---|---|---|
| index/middle/ring/little `mcp_abd` | about ±20° (unverified) | ±30 / ±20 | **−20…+20°** (middle ±15°) |
| `mcp_flex` | −45 (hyperextension)…+90 | −20…+110 / −15…+90 | **−10…+90°** |
| `pip` | 0…+100 | −20…+130 / 0…+90 | **−5…+100°** |
| `dip` | −10…+90 | coupled / 0…+90 | **−5…+80°** |
| thumb `cmc_rot` (opposition) | about 70° abduction arc | −53…+48 (CMC) / ±60 (TH5) | **−100…+40°** (keep v0) or −60…+60 |
| thumb `cmc_flex` | −20…+15 flexion, 70 abduction | 0…+70 (TH4) | **−15…+70°** |
| thumb `mcp_abd` | about ±10° (unverified) | ±45 / ±12 (TH3) | **−15…+15°** |
| thumb `mcp_flex` | 0…+50 (up to 60) | −20…+115 / ±40 (TH2) | **−10…+60°** |
| thumb `ip` | −20…+80 | −20…+100 / −15…+90 (TH1) | **−10…+80°** |

For comparison, functional daily-use ranges are much smaller: about MCP 61°, PIP 60°, DIP 39°, thumb MCP 21°, IP 18° (Hume et al. 1990, [PubMed 2324451](https://pubmed.ncbi.nlm.nih.gov/2324451/), recalled and not re-read). So a hand that hits the design ranges above covers daily tasks with margin.

---
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

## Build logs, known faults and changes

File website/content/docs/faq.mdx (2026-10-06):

---
title: FAQ
description: Honest answers to common questions about Tendra Hand, from why it uses tendons and one motor per joint to cost, licenses, AI and how to help.
updated: 2026-09-28
---

## What is the end goal?

A robot that can do what people do, just as well: cook, do chores, use tools. Not only pick things up, but understand a task and carry it out. The hand comes first, because almost everything useful we do goes through our hands, and it's the hardest part to get right. After the hand come touch and vision, AI that learns skills and understands tasks, and then an arm and a body. See the [roadmap](/project#roadmap).

## Why tendons instead of motors in the fingers?

Motors are heavy and bulky. Putting them in the fingers makes the fingers thick and slow, and every motor has to carry the ones further out. With tendons, the motors sit further back (in the palm now, and in the forearm later), and thin cords pull the joints. Human hands work the same way: most of the muscles that move your fingers are in your forearm.

## Why one motor per joint?

So every joint can move on its own. Many robotic hands save motors by linking joints together, so one motor bends a whole finger in a fixed pattern. That's simpler, but it can't do things like bending only the fingertip. Tendra Hand aims for the same freedom as a human hand, so each joint gets its own motor. A single tendon loop lets that one motor both close and open the joint.

## How many motors will the full hand need?

The prototype has 8 joints and 8 motors (thumb and index). The full five-finger hand is designed with **20** independently driven joints and 16 smart servos: 4 joints in each finger and 4 in the thumb. The fingertip joint of each finger has no servo of its own; it follows the middle joint through a small linkage. It isn't built yet.

## What does it cost to build?

We don't know yet, honestly. The current prototype uses cheap, common parts (28BYJ-48 steppers, ULN2003 boards, an ESP32-S3, PLA filament), but the smart servos in the next version cost more per joint. A costed parts list will be published on the [Hardware](/docs/hardware) page.

## Can I build one now?

Not from instructions yet. The software runs today (see [Getting started](/docs/getting-started)), and you can explore the hand in simulation. The print files, a full parts list and step-by-step assembly are being prepared while the first prototype is finished. Follow the [build log](/docs/log) for progress.

## Why steppers now and servos later?

The 28BYJ-48 steppers were cheap and on hand, which makes them great for a first prototype. But they don't report their position (so every joint must be straightened by hand before power-on), each needs four control pins, and they're slow. The planned **Feetech SCS0009** smart servos report their position, share one data cable, and remove manual homing. The firmware and Python code are built so the switch doesn't change anything above the motor driver.

## Does it use AI?

A little, and much more later. You can already control the simulated hand by moving your own hand in front of a webcam: an AI model finds your fingers in the camera image, and the software copies their angles to the robot ([how it works](/docs/software#webcam-control)). You can also set joint angles directly, from Python or with sliders in the simulator. The hand doesn't learn anything by itself yet. That comes in later phases: learning from recorded demonstrations, then training in simulation before moving to the real hand. See the [roadmap](/project).

## Do I need a powerful computer?

No. The simulation runs in MuJoCo on the CPU, and the project is developed on an ordinary laptop with integrated graphics. Heavy AI training later will use rented cloud GPUs.

## What license is it under?

Everything is open source, with a license that fits each kind of work:

- **Code** (firmware, Python, simulation, AI): Apache-2.0
- **Hardware** (CAD, print files, electronics): CERN-OHL-S-2.0
- **Docs and research**: CC BY 4.0

In short: you can use, build, change and even sell Tendra Hand. If you share a modified *hardware* design, you must share its design files under the same license. Please credit the project.

## How can I help?

Ideas, questions and bug reports are all welcome. Open an issue or a discussion on [GitHub](https://github.com/Danielloka/tendra-hand). Good places to start: try the simulation and report anything confusing in these docs, or share your experience with tendon-driven designs. See [Contribute](/contribute) for more.

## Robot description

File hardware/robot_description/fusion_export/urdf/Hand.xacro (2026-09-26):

<?xml version="1.0" ?>
<robot name="Hand" xmlns:xacro="http://www.ros.org/wiki/xacro">

<xacro:include filename="$(find Hand_description)/urdf/materials.xacro" />
<xacro:include filename="$(find Hand_description)/urdf/Hand.trans" />
<xacro:include filename="$(find Hand_description)/urdf/Hand.gazebo" />
<link name="base_link">
  <inertial>
    <origin xyz="-0.03777068462234341 0.02327196685078711 0.006594720592782829" rpy="0 0 0"/>
    <mass value="0.5460361346454996"/>
    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
  </inertial>
  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
</link>

<link name="Indexfix_1">
  <inertial>
    <origin xyz="2.2304717936030838e-05 0.006517871144740152 0.006450604350141623" rpy="0 0 0"/>
    <mass value="0.01603110386594604"/>
    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
  </inertial>
  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
</link>

<link name="Indexend_1">
  <inertial>
    <origin xyz="0.005500094052565433 0.00011252611470038282 0.01872282860307055" rpy="0 0 0"/>
    <mass value="0.041407323431063965"/>
    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
  </inertial>
  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
</link>

<link name="Indexmiddle_1">
  <inertial>
    <origin xyz="0.00551302966278297 0.00024944179119607 0.009722196457126825" rpy="0 0 0"/>
    <mass value="0.02101649364830199"/>
    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
  </inertial>
  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
</link>

<link name="Indextip_1">
  <inertial>
    <origin xyz="0.005493257746451662 -0.0002846037536686323 0.009522164207143607" rpy="0 0 0"/>
    <mass value="0.022704811734369713"/>
    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
  </inertial>
  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
</link>

<link name="Thumbroll_1">
  <inertial>
    <origin xyz="9.186167287673669e-05 -0.0013490725238598789 -0.02712996583655558" rpy="0 0 0"/>
    <mass value="0.03694987232707526"/>
    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
  </inertial>
  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
</link>

<link name="Thumbend_1">
  <inertial>
    <origin xyz="0.011004986490972316 -0.01762966389249578 -0.0006197567673547743" rpy="0 0 0"/>
    <mass value="0.05264211961831972"/>
    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
  </inertial>
  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
</link>

<link name="Thumbmiddle_1">
  <inertial>
    <origin xyz="0.005419702611819439 -0.014854927488871128 0.005230471286483964" rpy="0 0 0"/>
    <mass value="0.04992622344198199"/>
    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
  </inertial>
  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
</link>

<link name="Thumbtip_1">
  <inertial>
    <origin xyz="0.005111507331948879 -0.008822894678284787 0.005523429376397139" rpy="0 0 0"/>
    <mass value="0.03466320649263508"/>
    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
  </inertial>
  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
</link>

<joint name="Revolute 1" type="revolute">
  <origin xyz="-0.008531 0.012523 0.059976" rpy="0 0 0"/>
  <parent link="base_link"/>
  <child link="Indexfix_1"/>
  <axis xyz="-0.0 1.0 0.0"/>
  <limit upper="0.261799" lower="-0.261799" effort="100" velocity="100"/>
</joint>

<joint name="Revolute 2" type="revolute">
  <origin xyz="-0.0055 0.0065 0.019" rpy="0 0 0"/>
  <parent link="Indexfix_1"/>
  <child link="Indexend_1"/>
  <axis xyz="1.0 -0.0 0.0"/>
  <limit upper="1.658063" lower="-0.087266" effort="100" velocity="100"/>
</joint>

<joint name="Revolute 3" type="revolute">
  <origin xyz="0.0 0.0 0.04" rpy="0 0 0"/>
  <parent link="Indexend_1"/>
  <child link="Indexmiddle_1"/>
  <axis xyz="1.0 0.0 0.0"/>
  <limit upper="1.658063" lower="-0.087266" effort="100" velocity="100"/>
</joint>

<joint name="Revolute 4" type="revolute">
  <origin xyz="0.0 0.0 0.023" rpy="0 0 0"/>
  <parent link="Indexmiddle_1"/>
  <child link="Indextip_1"/>
  <axis xyz="1.0 0.0 0.0"/>
  <limit upper="1.658063" lower="-0.087266" effort="100" velocity="100"/>
</joint>

<joint name="Revolute 5" type="revolute">
  <origin xyz="0.001 0.015524 0.038476" rpy="0 0 0"/>
  <parent link="base_link"/>
  <child link="Thumbroll_1"/>
  <axis xyz="-0.0 0.0 -1.0"/>
  <limit upper="0.698132" lower="-1.745329" effort="100" velocity="100"/>
</joint>

<joint name="Revolute 6" type="revolute">
  <origin xyz="-0.011 -0.0055 -0.0271" rpy="0 0 0"/>
  <parent link="Thumbroll_1"/>
  <child link="Thumbend_1"/>
  <axis xyz="1.0 0.0 0.0"/>
  <limit upper="0.226893" lower="-1.396263" effort="100" velocity="100"/>
</joint>

<joint name="Revolute 7" type="revolute">
  <origin xyz="0.005697 -0.042 -0.005303" rpy="0 0 0"/>
  <parent link="Thumbend_1"/>
  <child link="Thumbmiddle_1"/>
  <axis xyz="0.707107 0.0 0.707107"/>
  <limit upper="0.087266" lower="-1.658063" effort="100" velocity="100"/>
</joint>

<joint name="Revolute 8" type="revolute">
  <origin xyz="0.0 -0.035 0.0" rpy="0 0 0"/>
  <parent link="Thumbmiddle_1"/>
  <child link="Thumbtip_1"/>
  <axis xyz="-0.707107 -0.0 -0.707107"/>
  <limit upper="1.658063" lower="-0.087266" effort="100" velocity="100"/>
</joint>

</robot>

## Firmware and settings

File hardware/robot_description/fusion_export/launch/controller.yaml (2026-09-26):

Hand_controller:
  # Publish all joint states -----------------------------------
  joint_state_controller:
    type: joint_state_controller/JointStateController
    publish_rate: 50

  # Position Controllers --------------------------------------
  Revolute 1_position_controller:
    type: effort_controllers/JointPositionController
    joint: Revolute 1
    pid: {p: 100.0, i: 0.01, d: 10.0}
  Revolute 2_position_controller:
    type: effort_controllers/JointPositionController
    joint: Revolute 2
    pid: {p: 100.0, i: 0.01, d: 10.0}
  Revolute 3_position_controller:
    type: effort_controllers/JointPositionController
    joint: Revolute 3
    pid: {p: 100.0, i: 0.01, d: 10.0}
  Revolute 4_position_controller:
    type: effort_controllers/JointPositionController
    joint: Revolute 4
    pid: {p: 100.0, i: 0.01, d: 10.0}
  Revolute 5_position_controller:
    type: effort_controllers/JointPositionController
    joint: Revolute 5
    pid: {p: 100.0, i: 0.01, d: 10.0}
  Revolute 6_position_controller:
    type: effort_controllers/JointPositionController
    joint: Revolute 6
    pid: {p: 100.0, i: 0.01, d: 10.0}
  Revolute 7_position_controller:
    type: effort_controllers/JointPositionController
    joint: Revolute 7
    pid: {p: 100.0, i: 0.01, d: 10.0}
  Revolute 8_position_controller:
    type: effort_controllers/JointPositionController
    joint: Revolute 8
    pid: {p: 100.0, i: 0.01, d: 10.0}

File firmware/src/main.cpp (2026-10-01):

// Tendra Hand firmware: low-level joint control over USB serial.
//
// Two hands, one protocol, chosen at build time (platformio.ini):
//   v0 (env tendra_s3):       8 joints, 28BYJ-48 steppers on ULN2003 boards  (config.h)
//   v1 (env hand_v1_servo):  16 joints, Feetech SCS0009 servos on one bus    (config_v1.h)
//
// The PC sends joint targets in radians; this firmware moves the motors there smoothly.
// Text protocol, one command per line (easy to test by hand in a serial monitor), N = joints:
//
//   P q1 q2 ... qN   set all joint targets [rad], motor order M1..MN
//   J i q            set target of joint i (1..N) [rad]
//   S                status -> "S q1 ... qN moving_mask"  (v1: measured positions)
//   F                feedback -> "F q,load,temp,volt ..." per joint (v1; "nan,0,0,0" if none)
//   X                stop all joints (smooth deceleration)
//   R                release all motors: coils off / servo torque off (joints go limp)
//   Z                current pose = zero (straighten all joints by hand first)
//   M i n            raw move joint i by n native units (steps/ticks), ignores limits (calibration)
//   K i s            set scale of joint i [native units per rad] (calibration)
//   V i v a          set max velocity [rad/s] and acceleration [rad/s^2] of joint i (0 = all)
//   B                (v1) scan the servo bus -> "B id id ..." (servos that answer a ping)
//   I                firmware info
//
// Replies: "OK", "ERR <reason>", or the requested data. Nothing moves until a command arrives.
#include <Arduino.h>

#include "motor_driver.h"

#if defined(TENDRA_HAND_V1)
#include "config_v1.h"
#include "scs0009_servo.h"
#include "scs_bus.h"
#include "scs_uart_port.h"
#else
#include "config.h"
#include "uln2003_stepper.h"
#endif

namespace {

#if defined(TENDRA_HAND_V1)
ScsUartPort g_port(Serial1);
ScsBus g_bus(g_port, kServoReplyTimeoutUs);
Scs0009Servo* g_servos[kNumJoints];  // created in setup()
uint32_t g_last_goal_ms = 0;
uint32_t g_last_poll_ms = 0;
int g_poll_next = 0;
#else
Uln2003Stepper g_steppers[kNumJoints] = {
    Uln2003Stepper(kJoints[0]), Uln2003Stepper(kJoints[1]), Uln2003Stepper(kJoints[2]),
    Uln2003Stepper(kJoints[3]), Uln2003Stepper(kJoints[4]), Uln2003Stepper(kJoints[5]),
    Uln2003Stepper(kJoints[6]), Uln2003Stepper(kJoints[7]),
};
#endif
// Code below only sees the HAL interface.
MotorDriver* g_joints[kNumJoints];

constexpr size_t kLineMax = 512;  // "P" with 16 values needs ~160 characters
char g_line[kLineMax];
size_t g_line_len = 0;

// Parse a 1-based joint index; returns 0-based index or -1.
int parseJoint(const char* token) {
  if (token == nullptr) return -1;
  const int i = atoi(token);
  return (i >= 1 && i <= kNumJoints) ? i - 1 : -1;
}

uint32_t offlineMask() {
  uint32_t mask = 0;
  for (int i = 0; i < kNumJoints; ++i) {
    if (!g_joints[i]->online()) mask |= 1ul << i;
  }
  return mask;
}

void printStatus() {
  Serial.print('S');
  uint32_t moving = 0;
  for (int i = 0; i < kNumJoints; ++i) {
    Serial.print(' ');
    Serial.print(g_joints[i]->position(), 4);
    if (g_joints[i]->isMoving()) moving |= 1ul << i;
  }
  Serial.print(' ');
  Serial.println(static_cast<unsigned long>(moving));
}

void printFeedback() {
  Serial.print('F');
  for (int i = 0; i < kNumJoints; ++i) {
    MotorFeedback fb;
    if (g_joints[i]->feedback(fb)) {
      Serial.printf(" %.4f,%.1f,%.0f,%.1f", fb.position_rad, fb.load_pct, fb.temperature_c,
                    fb.voltage_v);
    } else {
      Serial.print(" nan,0,0,0");
    }
  }
  Serial.println();
}

void printInfo() {
#if defined(TENDRA_HAND_V1)
  Serial.print("I tendra-hand fw " FIRMWARE_VERSION " hand=" HAND_VARIANT " joints=");
#else
  Serial.print("I tendra-hand fw " FIRMWARE_VERSION " joints=");
#endif
  Serial.print(kNumJoints);
  for (int i = 0; i < kNumJoints; ++i) {
    Serial.print(' ');
    Serial.print(kJoints[i].name);
    Serial.print(':');
    Serial.print(g_joints[i]->scale(), 2);
#if defined(TENDRA_HAND_V1)
    // name:ticks_per_rad:zero_ticks:online (copy calibrated zeros into config_v1.h)
    Serial.print(':');
    Serial.print(g_servos[i]->zeroTicks());
    Serial.print(':');
    Serial.print(g_joints[i]->online() ? 1 : 0);
#endif
  }
  Serial.println();
}

void releaseAll() {
#if defined(TENDRA_HAND_V1)
  g_bus.setTorque(scs::kBroadcastId, false);  // reaches every servo at once, even unknown ones
#endif
  for (MotorDriver* j : g_joints) j->release();
}

#if defined(TENDRA_HAND_V1)
void scanBus() {
  Serial.print('B');
  g_bus.setTimeout(1500);
  for (int id = 0; id <= scs::kMaxId; ++id) {
    if (g_bus.ping(static_cast<uint8_t>(id))) {
      Serial.print(' ');
      Serial.print(id);
    }
  }
  g_bus.setTimeout(kServoReplyTimeoutUs);
  Serial.println();
}

// Stream every changed goal to the bus in one SYNC WRITE.
void sendGoals() {
  uint8_t ids[kNumJoints];
  uint16_t ticks[kNumJoints];
  size_t n = 0;
  for (Scs0009Servo* s : g_servos) {
    if (s->torqueOn() && s->goalPending()) {
      ids[n] = s->id();
      ticks[n] = s->goalTicks();
      ++n;
      s->goalSent();
    }
  }
  if (n > 0) g_bus.syncWriteGoals(ids, ticks, n, kServoGoalTimeMs, kServoGoalSpeed);
}

// Read feedback of the next servo that is due (round robin).
void pollNext(uint32_t now_ms) {
  for (int k = 0; k < kNumJoints; ++k) {
    Scs0009Servo* s = g_servos[g_poll_next];
    g_poll_next = (g_poll_next + 1) % kNumJoints;
    if (s->pollDue(now_ms)) {
      s->poll(now_ms);
      return;
    }
  }
}
#endif

void handleLine(char* line) {
  char* save = nullptr;
  const char* cmd = strtok_r(line, " \t", &save);
  if (cmd == nullptr) return;
  auto next = [&]() { return strtok_r(nullptr, " \t", &save); };

  switch (toupper(cmd[0])) {
    case 'P': {
      float q[kNumJoints];
      for (int i = 0; i < kNumJoints; ++i) {
        const char* t = next();
        if (t == nullptr) {
          Serial.printf("ERR P needs %d values\n", kNumJoints);
          return;
        }
        q[i] = atof(t);
      }
      for (int i = 0; i < kNumJoints; ++i) g_joints[i]->setTarget(q[i]);  // offline: ignored
      const uint32_t offline = offlineMask();
      if (offline == 0) {
        Serial.println("OK");
      } else {
        Serial.printf("OK offline %lu\n", static_cast<unsigned long>(offline));
      }
      return;
    }
    case 'J': {
      const int i = parseJoint(next());
      const char* t = next();
      if (i < 0 || t == nullptr) break;
      if (!g_joints[i]->online()) {
        Serial.println("ERR joint offline");
        return;
      }
      g_joints[i]->setTarget(atof(t));
      Serial.println("OK");
      return;
    }
    case 'S':
      printStatus();
      return;
    case 'F':
      printFeedback();
      return;
    case 'X':
      for (MotorDriver* j : g_joints) j->stop();
      Serial.println("OK");
      return;
    case 'R':
      releaseAll();
      Serial.println("OK");
      return;
    case 'Z':
      for (MotorDriver* j : g_joints) {
        if (j->isMoving()) {
          Serial.println("ERR joints are moving");
          return;
        }
      }
      for (MotorDriver* j : g_joints) j->setZero();
      Serial.println("OK");
      return;
    case 'M': {
      const int i = parseJoint(next());
      const char* t = next();
      if (i < 0 || t == nullptr) break;
      if (!g_joints[i]->online()) {
        Serial.println("ERR joint offline");
        return;
      }
      g_joints[i]->moveRaw(atol(t));
      Serial.println("OK");
      return;
    }
    case 'K': {
      const int i = parseJoint(next());
      const char* t = next();
      if (i < 0 || t == nullptr || atof(t) <= 0) break;
      g_joints[i]->setScale(atof(t));
      Serial.println("OK");
      return;
    }
    case 'V': {
      const char* ti = next();
      const char* tv = next();
      const char* ta = next();
      if (ti == nullptr || tv == nullptr || ta == nullptr || atof(tv) <= 0 || atof(ta) <= 0) break;
      const int i = atoi(ti);
      if (i < 0 || i > kNumJoints) break;
      for (int k = 0; k < kNumJoints; ++k) {
        if (i == 0 || k == i - 1) g_joints[k]->setLimits(atof(tv), atof(ta));
      }
      Serial.println("OK");
      return;
    }
#if defined(TENDRA_HAND_V1)
    case 'B':
      scanBus();
      return;
#endif
    case 'I':
      printInfo();
      return;
  }
  Serial.println("ERR bad command (send I for info)");
}

void readSerial() {
  while (Serial.available() > 0) {
    const char c = static_cast<char>(Serial.read());
    if (c == '\n' || c == '\r') {
      if (g_line_len > 0) {
        g_line[g_line_len] = '\0';
        handleLine(g_line);
        g_line_len = 0;
      }
    } else if (g_line_len < kLineMax - 1) {
      g_line[g_line_len++] = c;
    } else {
      g_line_len = 0;  // line too long: drop it
      Serial.println("ERR line too long");
    }
  }
}

}  // namespace

void setup() {
#if defined(TENDRA_HAND_V1)
  // Safety first: every servo torque OFF before anything else (broadcast, no reply), then each
  // servo is switched off again individually and its position read. Nothing moves.
  g_port.begin(kServoBaud, kServoUartRxPin, kServoUartTxPin);
  g_bus.setTorque(scs::kBroadcastId, false);
  for (int i = 0; i < kNumJoints; ++i) {
    g_servos[i] = new Scs0009Servo(kJoints[i], g_bus);
    g_joints[i] = g_servos[i];
    g_joints[i]->begin();
  }
#else
  // Safety first: every motor pin LOW (coils off) before anything else runs.
  for (const JointConfig& j : kJoints) {
    for (uint8_t pin : j.pins) {
      pinMode(pin, OUTPUT);
      digitalWrite(pin, LOW);
    }
  }
  for (int i = 0; i < kNumJoints; ++i) {
    g_joints[i] = &g_steppers[i];
    g_joints[i]->begin();
  }
#endif
  Serial.begin(921600);  // native USB ignores the baud rate
}

void loop() {
  readSerial();
  const uint32_t now = micros();
  for (MotorDriver* j : g_joints) j->update(now);
#if defined(TENDRA_HAND_V1)
  const uint32_t now_ms = millis();
  if (now_ms - g_last_goal_ms >= kGoalPeriodMs) {
    g_last_goal_ms = now_ms;
    sendGoals();
  }
  if (now_ms - g_last_poll_ms >= kPollPeriodMs) {
    g_last_poll_ms = now_ms;
    pollNext(now_ms);
  }
#endif
}

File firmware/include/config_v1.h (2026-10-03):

// Tendra Hand V1 configuration: 16 Feetech SCS0009 servos (half-duplex TTL bus via the FE-URT-1)
// for 20 joints: the four finger DIPs are coupled passively to their PIPs, so the firmware never
// sees them. Used only by the `hand_v1_servo` build (TENDRA_HAND_V1). The v0 stepper hand keeps
// using config.h, unchanged.
//
// Keep in sync with the PC side (v1 joint table in software/tendra) and the v1 sim model.
#pragma once

#include <stdint.h>

#define FIRMWARE_VERSION "0.4.0"  // 0.4.0: 16 servos (DIP coupled to PIP), 5 mm spools, IDs renumbered
#define HAND_VARIANT "v1-servo"

constexpr int kNumJoints = 16;
constexpr float kDegToRad = 0.017453292519943295f;

// ----- Servo bus (ESP32-S3 UART1 -> FE-URT-1 -> servos) -----
// GPIO 17/18 are plain GPIOs on the ESP32-S3-N16R8: not strapping pins (0, 3, 45, 46), not
// USB (19, 20), not UART0 (43, 44), not flash/PSRAM (26-37), not the RGB LED (48).
// Wiring: ESP32 TX (GPIO 17) -> FE-URT-1 "TX" pin, ESP32 RX (GPIO 18) -> FE-URT-1 "RX" pin, GND to
// GND. Some FE-URT-1 boards have RX/TX silk-screened the wrong way round: if nothing answers
// (send B), swap the two wires.
constexpr int kServoUartTxPin = 17;
constexpr int kServoUartRxPin = 18;
constexpr uint32_t kServoBaud = 1000000;   // SCS0009 factory default
constexpr uint32_t kServoReplyTimeoutUs = 3000;

// ----- Motion -----
// Default joint-space limits (same as the v0 defaults: ~1.2 rad/s, ~2.5 rad/s^2).
constexpr float kDefaultMaxVelRad = 1.2f;   // rad/s
constexpr float kDefaultAccRad = 2.4f;      // rad/s^2
// Hard cap of the firmware's own ramp, in servo ticks/s (~117 deg/s at the servo horn).
constexpr float kServoMaxTicksPerS = 400.0f;
// Goal speed register value sent with every goal, a second (servo-side) speed limit. The firmware
// streams small goal steps, so this only matters if something goes wrong. Unit assumed to be
// ticks/s (Feetech SCSCL examples); 0 would mean "no limit", so it is never sent.
constexpr uint16_t kServoGoalSpeed = 600;
constexpr uint16_t kServoGoalTimeMs = 0;    // 0 = move at goal speed
// Goals are streamed to all servos with one SYNC WRITE this often.
constexpr uint32_t kGoalPeriodMs = 20;
// One servo's feedback (position, load, voltage, temperature) is read every kPollPeriodMs, round
// robin; offline servos are retried only every kOfflineRetryMs so they don't stall the loop.
constexpr uint32_t kPollPeriodMs = 2;
constexpr uint32_t kOfflineRetryMs = 1000;
constexpr uint8_t kMaxMissedReplies = 3;   // consecutive timeouts before a servo counts as offline

// Largest raw (uncalibrated, unclamped) move accepted by the M command, in servo ticks (~88 deg).
constexpr long kMaxRawMove = 300;

// Spool radius on the servo horn (m), the same on every servo. Informational: the scale that
// matters is servo_per_joint = r_joint_drum / r_spool (see servo_calibration.h).
constexpr float kDefaultSpoolRadius = 0.005f;  // 5 mm (2026-10-01, was 6 mm)

struct ServoJointConfig {
  const char* name;
  uint8_t servo_id;       // bus ID = motor number
  float min_rad;          // joint limits, positive = closing the hand
  float max_rad;
  bool invert;            // true if increasing servo ticks opens the joint
  float spool_radius_m;
  float servo_per_joint;  // servo radians per joint radian (calibration scale, default 1.0)
  int16_t zero_ticks;     // servo reading with the joint straight (q = 0); calibrate, then set here
};
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

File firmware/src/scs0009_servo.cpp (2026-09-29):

#include "scs0009_servo.h"

Scs0009Servo::Scs0009Servo(const ServoJointConfig& cfg, ScsBus& bus)
    : cfg_(cfg),
      bus_(bus),
      cal_{cfg.servo_per_joint * scs::kTicksPerRad, cfg.zero_ticks, cfg.invert} {
  profile_.setPosition(cfg.zero_ticks);
}

void Scs0009Servo::begin() {
  // Never move on boot: torque explicitly off, then only read where the servo is.
  bus_.setTorque(cfg_.servo_id, false);
  torque_on_ = false;
  goal_pending_ = false;
  applyLimits();
  poll(0);
}

void Scs0009Servo::update(uint32_t now_us) {
  if (!torque_on_) return;
  if (profile_.update(now_us) != 0) goal_pending_ = true;
}

void Scs0009Servo::poll(uint32_t now_ms) {
  last_poll_ms_ = now_ms;
  ScsFeedback fb;
  if (!bus_.readFeedback(cfg_.servo_id, fb)) {
    if (missed_ < 255) ++missed_;
    return;
  }
  fb_ = fb;
  fb_valid_ = true;
  missed_ = 0;
  // Limp joint (moved by hand, by a tendon, ...): the ramp starts from where it really is.
  if (!torque_on_) profile_.setPosition(fb_.position);
}

bool Scs0009Servo::pollDue(uint32_t now_ms) const {
  return online() || now_ms - last_poll_ms_ >= kOfflineRetryMs;
}

float Scs0009Servo::position() const {
  return cal_.ticksToJoint(online() ? fb_.position : profile_.position());
}

bool Scs0009Servo::feedback(MotorFeedback& out) const {
  if (!online()) return false;
  out.position_rad = cal_.ticksToJoint(fb_.position);
  out.load_pct = cal_.sign() * fb_.load * 0.1f;  // positive = pulling in the closing direction
  out.temperature_c = fb_.temperature_c;
  out.voltage_v = fb_.voltage_dv * 0.1f;
  out.error = fb_.error;
  return true;
}

bool Scs0009Servo::ensureTorque() {
  if (torque_on_) return true;
  if (!online()) return false;  // position unknown: switching on could jump
  // Hold exactly where the servo is, then switch torque on.
  const uint16_t here = fb_.position;
  profile_.setPosition(here);
  bus_.writeGoal(cfg_.servo_id, here, kServoGoalTimeMs, kServoGoalSpeed);
  if (!bus_.setTorque(cfg_.servo_id, true)) return false;
  torque_on_ = true;
  goal_pending_ = false;
  return true;
}

void Scs0009Servo::setTarget(float rad) {
  if (rad < cfg_.min_rad) rad = cfg_.min_rad;
  if (rad > cfg_.max_rad) rad = cfg_.max_rad;
  if (!ensureTorque()) return;
  profile_.setTarget(clampTicks(cal_.jointToTicks(rad), scs::kTicksMin, scs::kTicksMax));
}

void Scs0009Servo::moveRaw(long ticks) {
  if (ticks > kMaxRawMove) ticks = kMaxRawMove;
  if (ticks < -kMaxRawMove) ticks = -kMaxRawMove;
  if (!ensureTorque()) return;
  const long t = profile_.target() + (cfg_.invert ? -ticks : ticks);  // positive = closing
  profile_.setTarget(clampTicks(t, scs::kTicksMin, scs::kTicksMax));
}

void Scs0009Servo::setZero() {
  cal_.zero_ticks = online() ? fb_.position : profile_.position();
}

void Scs0009Servo::release() {
  bus_.setTorque(cfg_.servo_id, false);
  torque_on_ = false;
  goal_pending_ = false;
  profile_.setPosition(online() ? fb_.position : profile_.position());
}

void Scs0009Servo::setLimits(float max_vel_rad_s, float max_acc_rad_s2) {
  max_vel_rad_s_ = max_vel_rad_s;
  max_acc_rad_s2_ = max_acc_rad_s2;
  applyLimits();
}

void Scs0009Servo::setScale(float ticks_per_rad) {
  // Nothing moves: the goal stays at the same servo ticks, only the conversion changes.
  cal_.native_per_rad = ticks_per_rad;
  applyLimits();
}

void Scs0009Servo::applyLimits() {
  const float speed = max_vel_rad_s_ * cal_.native_per_rad;
  profile_.configure(speed < kServoMaxTicksPerS ? speed : kServoMaxTicksPerS,
                     max_acc_rad_s2_ * cal_.native_per_rad);
}

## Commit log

2026-09-26 Set up Tendra Hand project structure
    - Add CLAUDE.md with project context, hardware, pin map and conventions
    - Move Fusion 360 URDF export to hardware/robot_description/fusion_export
    - Add folder structure with READMEs (hardware, firmware, sim, software,
    docs, research, website)
    - Add root README, roadmap and research log
    - Add licenses: Apache-2.0 (code), CERN-OHL-S-2.0 (hardware),
    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
    [Hand.xacro, Indexend_1.stl, Indexfix_1.stl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]
2026-09-26 Add MuJoCo model, converter and viewer
    - pyproject.toml + uv.lock: Python 3.12 environment (mujoco, numpy; pytest, ruff)
    - sim/convert.py: Fusion URDF export -> sim/models/tendra_hand.xml with
    PLA masses, mesh-based inertia, descriptive joint names,
    closing-positive sign convention, position actuators in motor order,
    and contact excludes for palm-welded/hull artifacts
    - sim/view.py: interactive viewer with a slider per motor
    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
2026-09-26 Tidy repo root and record spool radius
    - Move pytest/ruff caches into .venv
    - Record 1 cm spool radius and confirmed motor mapping in CLAUDE.md
2026-09-26 Add firmware v0.1: stepper HAL, smooth motion, serial protocol
    - PlatformIO project for ESP32-S3-N16R8 (16 MB flash, PSRAM disabled,
    USB CDC on boot)
    - MotorDriver HAL interface in joint radians; Uln2003Stepper driver
    (half-step, idle coil release, phase-continuous re-zeroing)
    - Trapezoidal MotionProfile with mid-move retargeting, plus PC-side
    unit tests
    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
2026-09-27 Add tendra Python package and digital twin v1
    - software/tendra: Hand interface with SimHand (MuJoCo) and RealHand
    (USB serial to firmware), calibration helpers, FakeEsp32 emulator
    - sim/twin.py: MuJoCo sliders drive the real (or fake) hand,
    rate-limited and only on change; shows real-vs-sim difference
    - Tests: protocol, clamping, calibration, sim tracking, twin bridge,
    and joint names/limits consistency across Python, firmware and MJCF
    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
2026-09-28 Route index tendons through the joint axes
    Pass-through tendons now cross every index joint exactly on its axis, so
    their length no longer depends on the joint angle (no coupling):
    - PIP: plug with a 1.2 mm hole on the axis (TendraPipPinch)
    - MCP flex: plug with a 1.4 mm hole on the axis (TendraIndexPinch)
    - MCP sideways: 1 mm slit on the axis, edges filleted 0.4 mm
    Adds the Fusion scripts, the OpenCASCADE experiments behind them, the
    joint-zero STEP export and the research log entries. Not yet printed.
    [Hand assebly.step]
2026-09-28 Add rigged real hand model and motion toggle to the website
    - Convert the STEP to a rigged hand.glb (step-to-glb.py); joints sit at
    the URDF pivots with the sim's closing-positive signs
    - Hero layout and scroll story: hand glides into the right column and
    turns with the scroll
    - "Play animation" button for visitors with reduced motion
    - Fix thumb_cmc_rot range to the real +40 deg limit
    - Record the work in CLAUDE.md and the research log
2026-09-29 Add Tendra Hand V1 design, servo firmware, v1 sim, teleop, media and AI research
    Full 21-DOF V1 (SCS0009) Fusion scripts, tendon router, MJCF model, servo
    bus firmware, webcam teleop and retargeting, media library, website project
    page with V1 model, and research notes.
    [Hand assebly.step, forearm.stl, index_base.stl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]
2026-09-29 Rework V1 thumb routing, add calibration, update firmware, sim and docs
    [forearm.stl, palm.stl, servo_06_thumb_mcp_flex.stl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]
2026-10-01 Add grasp RL, synergies, GPU sim work, hand research; re-slot V1 servos
    Work in progress up to 2026-10-01: 4-DOF thumb servo IDs (9..20), thumb
    routing, grasp RL environment and PPO, finger synergies, GPU physics
    experiments, V0 5 mm spool, and the state-of-the-art hand research in
    research/references/hands/.
    [forearm.stl, palm.stl, servo_09_middle_dip.stl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]
2026-10-01 Couple V1 finger DIPs to their PIPs: 16 servos, 5 mm spools
    Each finger's DIP now follows its PIP (DIP = 0.75 x PIP) through a passive
    coupling tendon: the DIP strands are tied in the proximal phalanx and wrap a
    4.5 mm hub on the PIP axis, crossed in the middle phalanx. V1 keeps 20 joints
    on 16 SCS0009 servos (IDs renumbered, firmware 0.4.0). All spools are now
    5 mm; finger knuckle drums 7 mm, so servo_per_joint is 1.4 (mcp_flex),
    1.5 (thumb_cmc_rot) and 1.2 elsewhere.
    - Router: 32 strands, finger abduction servos moved to the freed deeper slot
    - Sim: joint equality for the physics plus passive coupling strands whose
    constant length proves the 0.75 ratio; fist keyframe qpos order fixed
    -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
    [config_v1.h, convert_v1.py, fake_esp32.py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]
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2026-10-02 Couple V1 DIPs to PIPs with a rigid linkage instead of a tendon
    One bar per finger crosses the middle phalanx (pin A on the proximal
    phalanx, pin B on the distal phalanx). dip_linkage.py finds each finger's
    pin positions from its middle-phalanx length, keeping the bar inside the
    phalanx, clear of both axes and away from toggle; DIP stays within 0.6 deg
    of 0.75 x PIP over the whole range. The router writes the designs into
    tendon_routes.json; the sim uses the fitted DIP(PIP) quartic in the joint
    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
2026-10-02 Add Tendra arm sim: OpenArm shoulder and elbow, forearm twist, 2-way wrist, V1 hand
    The wrist model puts the V1 hand on its forearm with a gimbal wrist; every servo
    strand runs through the wrist centre (PTFE sheaths), so wrist motion never changes
    a strand length. tendra.arm attaches it to OpenArm v2's right shoulder and elbow
    (openarm-mujoco 2.3.0 as a dependency). Viewer options --wrist and --arm.
2026-10-02 Train the hand on the arm: IK-driven wrist in the grasp scene and RL env
    SceneConfig(arm=True) and GraspEnvConfig(arm=True) hold the wrist with OpenArm's
    shoulder and elbow plus Tendra's forearm and wrist instead of a floating weld.
    The policy action is unchanged; ArmIK (damped least squares, any model and joint
    list) turns the wrist target into joint targets, so the arm can be swapped for
    the owner's own design later. Gravity-compensated arm, start pose with the elbow
    out, reachable spawn box, ARM_GRASP for the scripted cube and ball grasps,
    arm joints in the observation and an arm-limit penalty. train_grasp.py and
    eval_grasp.py get --arm; datasets record the arm joints.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
    [arm.py, grasp_env.py, scene.py]
2026-10-02 Two arms, a mirrored left hand, no floating hand
    Remove the floating hand: the grasp scene and RL env run on the arm only, now with two
    OpenArm arms and a left hand mirrored from the right (mirror_export.py, --side converters).
    One hand works per episode (hands=right|left|any); the left is seen through a mirror so one
    policy drives both. IK runs on a bare kinematic copy. Webcam teleop and the GPU path are
    disabled until ported. Docs updated.
    [forearm.stl, index_base.stl, index_distal.stl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]
2026-10-03 Align docs, website and BOM with 16 servos and the DIP linkage
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2026-10-16 Add calm-control settings for grasp RL to stop policy shaking
    Filtered wrist command, action-rate/jerk/still rewards, finger and wrist
    ramps, action delay, damped arm servos, CAPS loss for GPU training and a
    deploy-time filter (tendra.calm); legacy config values keep old policies
    running as trained. Research notes in research/ai/smooth-control.md.
2026-10-16 Make the website visionary and replace Contribute with Contact
    Rewrite the home hero, story chapters, stats and project page around the
    goal instead of specs and licenses; cut the roadmap to five big milestones
    on home and project; remove the Contribute page (redirect /contribute to
    /contact) and add a Contact page with X, Instagram and email placeholders.
    Accessibility and design fixes from review, and keyed MDX nodes on
    one-paragraph pages.
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2026-10-19 Redesign contact cards and add a copy-email button
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

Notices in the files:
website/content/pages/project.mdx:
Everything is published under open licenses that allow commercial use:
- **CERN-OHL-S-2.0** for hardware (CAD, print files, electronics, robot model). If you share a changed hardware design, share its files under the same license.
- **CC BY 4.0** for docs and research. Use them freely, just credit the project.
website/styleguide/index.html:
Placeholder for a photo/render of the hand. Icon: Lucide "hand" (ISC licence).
